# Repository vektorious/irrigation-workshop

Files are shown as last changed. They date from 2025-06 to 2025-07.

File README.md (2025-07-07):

   # Irrigation Workshop

## Introduction
In this workshop, we will build an automated plant watering system. It will consist of four key components:
1. Sensor – measures soil moisture
2. Pump – delivers water to the plant
3. Controller – reads sensor data and controls the pump
4. Interface – let's you control and monitor the system

Together, these parts create a responsive system that waters a plant only when it needs it.

### Soil Moisture Sensors

#### Overview

| Sensor Type | Measurement Principle | Advantages | Limitations |
|---|---|---|---|
| Capacitive | Measures dielectric constant of the soil | Durable, accurate | Sensitive to nearby objects and interference |
| Resistive | Measures electrical resistance | Cheap, easy to use | Corrodes over time (potentially toxic) |

In addition to resistive and capacitive sensors, there are more advanced methods used in agriculture and research, such as tensiometers, Time Domain Reflectometry or Frequency Domain Reflectometry TDR/FDR sensors, and thermal or capillary-based systems. These offer higher accuracy or different measurement principles (like soil water tension) but are often more complex or expensive.

#### DIY Sensors

Tension Sensors (e.g. Tensiometer, Capillary Sensor)
- Measure how tightly water is held in the soil.
- Simulate what plants "feel" when extracting water.
- Use porous ceramic tips and water-filled tubes to show suction or pressure changes.
- analog output but requires pressure sensor to read electronically -> fun but complex to integrate.

Resistive Sensors (e.g. Nail Electrodes, Gypsum Block)
- Measure electrical resistance between two conductors.
- Moist soil conducts better, dry soil worse (but soil type/quality has an impact too!).
- Simple to build with nails, wires, or embedded in gypsum for more stability.
- analog output (voltage) which is very easy to read with microcontrollers -> simple and easy to integrate.

Tensiometers provide more biologically meaningful data, but are harder to read electronically. Resistive sensors are easier to connect and automate, making them ideal for basic watering systems.

#### Workshop Sensor Choice
For this workshop I recommend using the an off-the-shelf capacitive sensor. They are are more stable and durable than resistive ones. They don’t corrode as quickly, provide smoother readings, and are widely available as well as affordable. This makes them ideal for beginner projects and long-term use in automated watering systems. There are standard sensors that are sold by various shops (see image below). However, they are often faulty. Check this video before you buy some: [Capacitive Soil Moisture Sensors don't work correctly + Fix for v2.0 v1.2 Arduino ESP32 Raspberry Pi](https://www.youtube.com/watch?app=desktop&v=IGP38bz-K48)

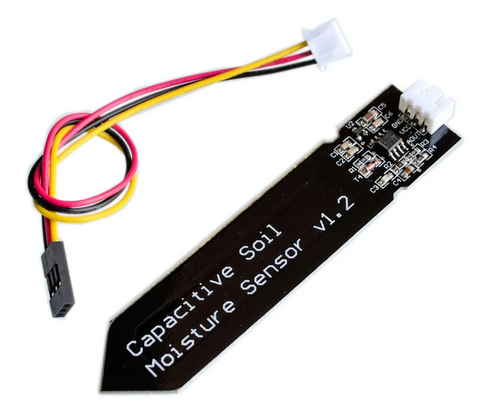
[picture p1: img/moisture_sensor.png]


### Pump Systems

| Pump Type | Working Principle | Advantages | Suitable For |
|---|---|---|---|
| Submersible Pump  | Impeller submerged in water reservoir | High flow rate, robust | Raised beds, greenhouses |
| Diaphragm Pump | Oscillating membrane creates pressure/vacuum  | Stable pressure, self-priming | Distributed watering systems |
| Peristaltic Pump  | Fluid pushed through flexible tube by rollers | Precise dosage, no backflow | Potted plants, indoor setups |

For this workshop, we will use a diaphragm pump. They are reliable, self-priming, and can handle small amounts of water with consistent pressure. They work well in compact systems and are easy to control with a relay or MOSFET. Their sealed design also makes them less prone to leaking or clogging — perfect for small-scale automated irrigation projects.

### Controlling the Pump

Microcontrollers like ESP32 or Arduinos cannot power pumps directly. You need an electronic switch that can handle higher current. There are two common ways to do this: Using a relay or a MOSFET.

| Feature | Relay Module | MOSFET Module |
|---|---|---|
| Switching type | Mechanical (electromagnetic switch) | Electronic (transistor-based) |
| Sound | Audible “click” when switching | Silent |
| Speed | Slow switching (ms range) | Fast switching (μs range), suitable for PWM |
| Load types | Good for AC and DC | Typically used for DC only |
| Efficiency | Some power loss (mechanical contact) | High efficiency, low heat generation |
| Use case example | Simple on/off pump control | Precise or PWM pump control (e.g. speed) |
| Complexity | Easy to wire and understand | Requires correct polarity and pin setup |

For this workshop, we will use a MOSFET (IRLB8721PbF). This logic-level MOSFET can be triggered directly from a microcontroller (e.g. Arduino or micro:bit) and is capable of switching up to 24 V DC and 10 A — more than enough for most small pumps or valves. It's silent, efficient, and ideal for low-voltage DC systems.
While the pumps used in this setup typically draw far less current (around 500 mA), using a higher-rated MOSFET gives us more flexibility. It ensures that the same circuit can also be used safely with larger pumps or other components in future projects.

(Wiring example check [here](https://learn.adafruit.com/rgb-led-strips/usage)) 

NOTE: Pico AND MOSFET/Pump Power Source MUST HAVE THE SAME GROUND!!

### Adding an LED strip as part of the interface

As part of this workshop, we held an open design session with some of the participants before the hands-on activities began. One of their suggestions was to add an LED strip with 10 individually controllable LEDs to visualize the soil moisture level.

We use a WS2812B (NeoPixel-compatible) LED strip, which allows for precise color and brightness control using a single data pin from the microcontroller. 

## Setup and Code

### Wiring the components

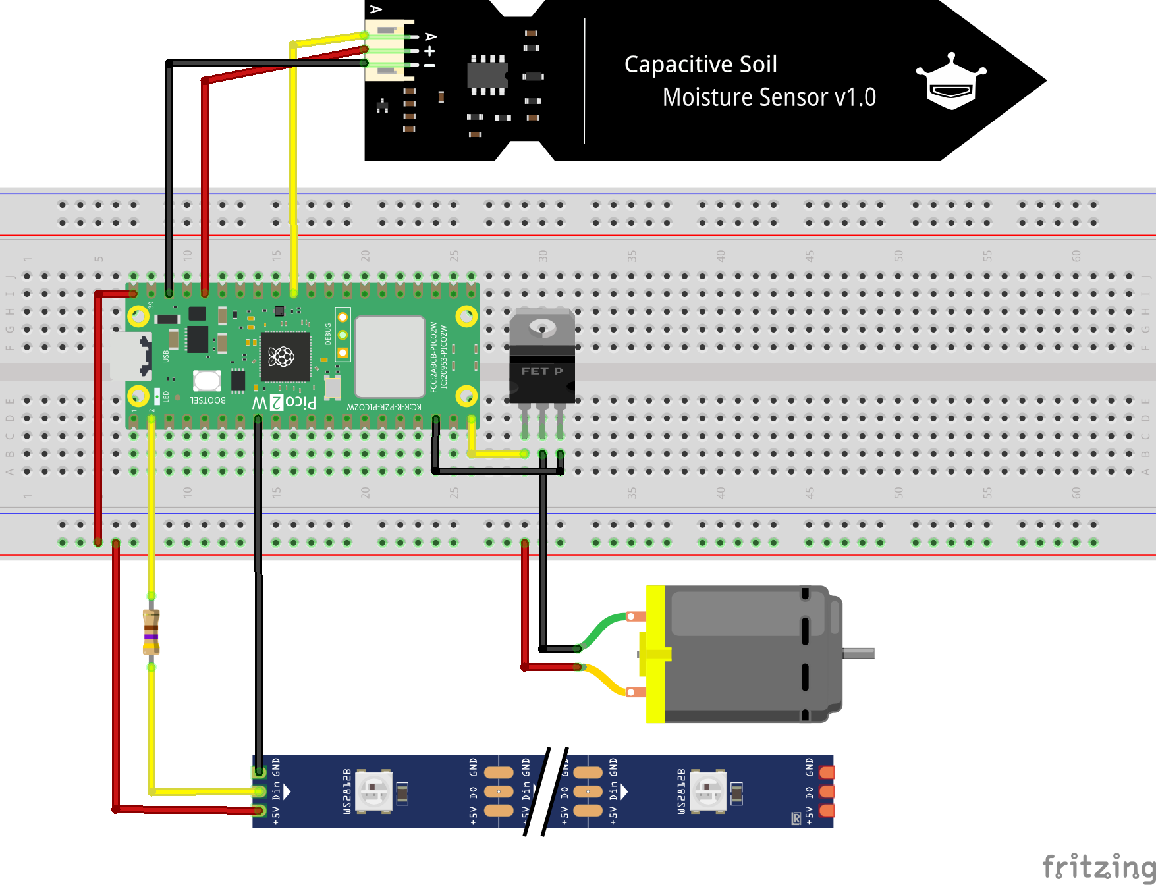
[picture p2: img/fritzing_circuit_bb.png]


### Switch GPIO output on and off

```python
import machine
import time

# Set the pump control pin
PUMP_PIN = 15  # Use GPIO15, change if needed
pump = machine.Pin(PUMP_PIN, machine.Pin.OUT)

def pump_on():
    pump.value(1)  # Set pin HIGH to turn pump ON
    print("Pump ON")

def pump_off():
    pump.value(0)  # Set pin LOW to turn pump OFF
    print("Pump OFF")

# Simple test sequence
while True:
    print("Turning pump ON for 3 seconds...")
    pump_on()
    time.sleep(3)
        
    print("Turning pump OFF for 3 seconds...")
    pump_off()
    time.sleep(3)

```

### Reading Sensor Data

```python
from machine import Pin, ADC
from time import sleep

soil = ADC(Pin(26))

while True:
  soil_value = soil.read_u16() # read value, 0-65535 across voltage range 0.0v - 3.3v
  soil_voltage = (soil_value/65535)*3.3
  print(soil_voltage) 
  sleep(1)

```

### Test LED strips

```python

import machine
import neopixel
import time

# Configuration
NUM_LEDS = 10
PIN = 1
BRIGHTNESS = 100  # 0–255

np = neopixel.NeoPixel(machine.Pin(PIN), NUM_LEDS)

# Helper: apply brightness to RGB
def scale_color(r, g, b, brightness):
    factor = brightness / 255
    return int(r * factor), int(g * factor), int(b * factor)

# Helper: turn off all LEDs
def clear_strip():
    for i in range(NUM_LEDS):
        np[i] = (0, 0, 0)
    np.write()

# List of colors to cycle through
colors = [
    (255, 0, 0),   # Red
    (0, 255, 0),   # Green
    (0, 0, 255)    # Blue
]

# Main running light loop
try:
    color_index = 0
    while True:
        r, g, b = colors[color_index]
        r, g, b = scale_color(r, g, b, BRIGHTNESS)

        # Forward direction
        for i in range(NUM_LEDS):
            clear_strip()
            np[i] = (r, g, b)
            np.write()
            time.sleep(0.1)

        # Backward direction
        for i in range(NUM_LEDS - 2, 0, -1):
            clear_strip()
            np[i] = (r, g, b)
            np.write()
            time.sleep(0.1)

        # Next color
        color_index = (color_index + 1) % len(colors)

except KeyboardInterrupt:
    clear_strip()
    print("Running light stopped.")

```

### Test all Hardware

```python
import machine
import neopixel
import time

# === Configuration ===
ADC_PIN = 26               # GP26 = ADC0
NEOPIXEL_PIN = 1           # GP1
NUM_LEDS = 10
BRIGHTNESS = 0.2           # Scale 0–1

PUMP_PIN = 15              # GP15 for pump
MOISTURE_THRESHOLD = 30.0  # in percent
PUMP_DURATION = 1          # in seconds

MAX_VOLTAGE = 3.0          # Voltage at driest
MIN_VOLTAGE = 0.5          # Voltage at wettest

# === Setup ===
adc = machine.ADC(ADC_PIN)
np = neopixel.NeoPixel(machine.Pin(NEOPIXEL_PIN), NUM_LEDS)

pump = machine.Pin(PUMP_PIN, machine.Pin.OUT)
pump.value(0)  # Ensure pump is off

# === Helper Functions ===

def read_voltage():
    raw = adc.read_u16()  # Range: 0–65535
    voltage = (raw / 65535) * 3.3
    return voltage

def map_voltage_to_percent(voltage):
    voltage = max(min(voltage, MAX_VOLTAGE), MIN_VOLTAGE)
    percent = (MAX_VOLTAGE - voltage) / (MAX_VOLTAGE - MIN_VOLTAGE) * 100
    return round(percent, 1)

def get_color(percent):
    if percent <= 30:
        return (255, 0, 0)         # Red
    elif percent <= 50:
        return (255, 180, 0)       # Yellow
    else:
        return (0, 255, 0)         # Green

def show_leds(percent):
    leds_on = round(percent / 100 * NUM_LEDS)
    color = get_color(percent)
    for i in range(NUM_LEDS):
        np[i] = color if i < leds_on else (0, 0, 0)
    np.write()

# === Main Loop ===
COOLDOWN = 5  # seconds to wait before retrying pump

try:
    while True:
        voltage = read_voltage()
        percent = map_voltage_to_percent(voltage)
        print("Moisture: {:.1f}% (Voltage: {:.2f} V)".format(percent, voltage))
        
        show_leds(percent)

        if percent < MOISTURE_THRESHOLD:
            print("Moisture below threshold — starting pump.")
            pump.value(1)
            time.sleep(PUMP_DURATION)
            pump.value(0)
            print("Pump stopped.")
            print("Waiting for moisture to improve...")
            time.sleep(COOLDOWN)
        else:
            time.sleep(1)

except KeyboardInterrupt:
    print("Stopped by user.")
    pump.value(0)
    for i in range(NUM_LEDS):
        np[i] = (0, 0, 0)
    np.write()

```

## Interfaces

## Similar Projects

### Self-Watering Flower Pot "Flaura"
This 3D-printable self-watering flower pot project integrates a soil moisture sensor, a microcontroller (ESP8266), and a small water pump to automate plant care. It also includes a mobile app interface using Blynk, allowing users to monitor soil moisture and trigger manual watering remotely.

https://www.thingiverse.com/thing:4921885

### Watering System without microcontroller
This project builds a simple automatic plant watering system without using a microcontroller. It uses soil probes to detect moisture, a BC547 transistor to trigger a relay, and a small water pump. When the soil is dry, the pump automatically turns on; when the soil is wet, it turns off. It's a low-cost solution with no programming required.

https://circuitdigest.com/electronic-circuits/automatic-plant-watering-system-without-arduino

### Elecrow Smart Plant

A compact IoT plant monitor built around an ESP32‑S2 microcontroller, featuring a built‑in capacitive soil moisture probe, ambient light and air temperature/humidity sensors, and an optional 2.9″ e‑paper display for live data. It streams data over Wi‑Fi (compatible with Home Assistant via ESPHome) and is ideal for visualizing plant health, though it does not include a pump or watering system

https://www.elecrow.com/smart-plant.html

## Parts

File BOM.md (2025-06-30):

Soil Moisture Sensor, https://www.berrybase.de/analoger-kapazitiver-bodenfeuchtesensor
Rasberry Pi Pico 2W, https://www.berrybase.de/raspberry-pi-pico-2w-rp2350-wlan-bluetooth-mikrocontroller-board
Micro-USB Cable, https://www.berrybase.de/offizielles-raspberry-pi-micro-usb-kabel-schwarz-1-0m
BME280 Sensor, https://www.berrybase.de/gy-bme280-breakout-board-3in1-sensor-fuer-temperatur-luftfeuchtigkeit-und-luftdruck
Circuit Board, https://www.berrybase.de/lochrasterplatine-doppelseitig-3x7cm-10-stueck
Drehpotentiometer, https://www.berrybase.de/drehpotentiometer-100ko-horizontal-mono-6mm-loetoesen
Photoresistor, https://www.berrybase.de/5506-ldr-fotowiderstand-90mw-2-6ko-540nm-tht
MOSFET (IRLB8721PbF)
Membrane Pump (5 VDC)

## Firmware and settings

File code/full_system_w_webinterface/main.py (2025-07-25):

import network, ujson, utime, machine, urequests, socket, gc
from neopixel import NeoPixel
from machine import Pin, ADC, Timer
import ntptime

# === setup pins ===
MOISTURE_PIN = ADC(26)  # A0
PUMP_PIN = Pin(15, Pin.OUT)
LED_PIN = Pin(1, Pin.OUT)
NUM_LEDS = 10
np = NeoPixel(LED_PIN, NUM_LEDS)

# === Globale Variablen ===
history = []
last_pump_time = None
pump_history = []
config = {}

# === load config ===
def load_config():
    global config, mode
    try:
        with open("config.json", "r") as f:
            config = ujson.load(f)
    except:
        import config as fallback
        config = fallback.default_config
    mode = config.get("mode", "interval")

# === WiFi connection ===
def connect_wifi():
    import secrets
    print("connecting to WiFi")
    wlan = network.WLAN(network.STA_IF)
    wlan.active(True)
    wlan.connect(secrets.WIFI_SSID, secrets.WIFI_PASSWORD)
    while not wlan.isconnected():
        utime.sleep(0.5)
    print("WiFi connected:", wlan.ifconfig())
    ntptime.settime()

# === Measurements ===
def read_moisture():
    raw = MOISTURE_PIN.read_u16() * 3.3 / 65535
    min_v = config["min_voltage"]
    max_v = config["max_voltage"]
    percent = max(0, min(100, 100 * (max_v - raw) / (max_v - min_v)))
    return round(percent, 1), round(raw, 2)

# === updated LEDs ===
def update_leds(percent):
    num_on = round(NUM_LEDS * percent / 100)
    for i in range(NUM_LEDS):
        if i < num_on:
            if percent < config["low_threshold"]:
                np[i] = (255, 0, 0)
            elif percent < config["medium_threshold"]:
                np[i] = (255, 150, 0)
            else:
                np[i] = (0, 255, 0)
        else:
            np[i] = (0, 0, 0)
    np.write()

# === send data via API ===
def send_data(percent, voltage):
    try:
        import secrets
        headers = {"x-api-key": secrets.API_KEY}
        data = {
            "name": config["name"],
            "sensors": {
                "moisture": {
                    "value": percent,
                    "unit": "%"
                    },
                "moisture-voltage": {
                    "value": voltage,
                    "unit": "V"
                    }
                }
            }
        r = urequests.post(secrets.API_URL + "/measurements", headers=headers, json=data)
        print("Status code:", r.status_code)
        r.close()
    except Exception as e:
        print("API error:", e)

def notify_pump():
    try:
        import secrets
        headers = {"x-api-key": secrets.API_KEY}
        data = {"name": config["name"]}
        r = urequests.post(secrets.API_URL + "/pump", headers=headers, json=data)
        print("Status code:", r.status_code)
        r.close()
    except Exception as e:
        print("Pump notify error:", e)

# === pump control ===
def activate_pump():
    global last_pump_time
    last_pump_time = utime.time()
    pump_history.append(last_pump_time)
    if len(pump_history) > 10:
        pump_history.pop(0)
    duration = config["pump_duration"]
    print("activating pump")
    PUMP_PIN.on()
    utime.sleep(duration)
    PUMP_PIN.off()
    last_pump_time = utime.time()
    notify_pump()
    

# === watering decision ===
def check_watering(percent):
    if percent < config["moisture_threshold"]:
        # z. B. max. 1x pro Stunde gießen
        now = utime.time()
        if not last_pump_time or (now - last_pump_time) > 3600:
            activate_pump()

# === start measurement ===
def measure_and_act():
    global history
    percent, voltage = read_moisture()
    print("Feuchtigkeit:", percent, "% (", voltage, "V)")
    update_leds(percent)
    send_data(percent, voltage)
    history.append((percent, voltage, utime.time()))
    if len(history) > 10:
        history.pop(0)
    check_watering(percent)

# === check time (scheduler mode) ===
def should_run_now():
    now = utime.localtime(utime.time()+ int(2 * 3600)) # UTC offset * seconds
    hhmm = "{:02}:{:02}".format(now[3], now[4])
    print(hhmm)
    return hhmm in config["daily_times"]

# === webinterface ===
def start_webserver():
    import json
    addr = socket.getaddrinfo('0.0.0.0', 80)[0][-1]
    s = socket.socket()
    s.bind(addr)
    s.listen(1)
    print("Web interface active…")

    while True:
        try:
            cl, _ = s.accept()
            req = cl.recv(1024).decode()
            print("Request:", req.split("\r\n")[0])

            if "GET /data" in req:
                response = {
                    "history": history,
                    "last_pump": last_pump_time,
                    "pump_history": pump_history,
                    "mode": mode
                }
                body = json.dumps(response)
                cl.send("HTTP/1.0 200 OK\r\nContent-Type: application/json\r\n\r\n" + body)

            elif "POST /update" in req:
                length = 0
                for line in req.split("\r\n"):
                    if line.startswith("Content-Length:"):
                        length = int(line.split(":")[1].strip())
                        break
                body = cl.recv(length).decode()
                updates = json.loads(body)
                config.update(updates)
                with open("config.json", "w") as f:
                    json.dump(config, f)
                cl.send("HTTP/1.0 200 OK\r\n\r\nOK")

            elif "POST /pump" in req:
                activate_pump()
                cl.send("HTTP/1.0 200 OK\r\n\r\nPump started")

            elif "GET /" in req or "GET /index.html" in req:
                cl.send("HTTP/1.0 200 OK\r\nContent-Type: text/html\r\n\r\n")
                try:
                    with open("index.html", "r") as f:
                        for line in f:
                            cl.send(line)
                except Exception as e:
                    print("HTML file error:", e)
                    cl.send("Error loading page.")

            else:
                cl.send("HTTP/1.0 404 Not Found\r\n\r\nNot found")

        except Exception as e:
            print("Unhandled error in webserver thread:", e)

        finally:
            try:
                cl.close()
            except:
                pass
            gc.collect()


# === main loop ===
load_config()
connect_wifi()

# run webinterface in the background
import _thread
_thread.start_new_thread(start_webserver, ())

# scheduler for measurements
last_measure = 0

while True:
    now = utime.time()

    if mode == "test":
        if now - last_measure >= 10:
            measure_and_act()
            last_measure = now

    elif mode == "interval":
        interval_seconds = int(config.get("interval_hours", 1) * 3600)
        if now - last_measure >= interval_seconds:
            measure_and_act()
            last_measure = now

    elif mode == "daily":
        # Only run if we're within a minute of a desired time
        if should_run_now():
            if now - last_measure >= 60:
                measure_and_act()
                last_measure = now

    utime.sleep(5)  # small delay to avoid burning CPU

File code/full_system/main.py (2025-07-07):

# main.py – Pico main loop
import machine
import time
from config import load_config
from secrets import SECRETS
from http_client import post_moisture, post_pump_event
import neopixel

# === Setup ===
config = load_config()

DEVICE_NAME = config["device_name"]
MODE = config["mode"]
THRESHOLD = config["moisture_threshold"]
PUMP_DURATION = config["pump_duration"]
INTERVAL = config["measure_interval"]
MAX_VOLTAGE = config.get("max_voltage", 3.0)
MIN_VOLTAGE = config.get("min_voltage", 0.5)
LOW_THRESHOLD = config.get("low_threshold", 30)
MEDIUM_THRESHOLD = config.get("medium_threshold", 50)
LED_BRIGHTNESS = config.get("led_brightness", 1.0)  # scale 0.0–1.0

adc = machine.ADC(26)
pump = machine.Pin(15, machine.Pin.OUT)
pump.value(0)

np = neopixel.NeoPixel(machine.Pin(1), 10)  # GP1, 10 LEDs

# === WiFi Setup ===
import network
wlan = network.WLAN(network.STA_IF)
wlan.active(True)
wlan.connect(SECRETS["wifi_ssid"], SECRETS["wifi_password"])

print("Connecting to WiFi...")
while not wlan.isconnected():
    time.sleep(0.5)
print("Connected, IP:", wlan.ifconfig()[0])

# === Helper Functions ===
def read_moisture():
    voltage = adc.read_u16() / 65535 * 3.3
    voltage = max(min(voltage, MAX_VOLTAGE), MIN_VOLTAGE)
    percent = (MAX_VOLTAGE - voltage) / (MAX_VOLTAGE - MIN_VOLTAGE) * 100
    return round(percent, 1), round(voltage, 2)

def run_pump():
    print("Pump ON")
    pump.value(1)
    time.sleep(PUMP_DURATION)
    pump.value(0)
    print("Pump OFF")
    post_pump_event()

def scale_color(rgb, brightness):
    return tuple(int(c * brightness) for c in rgb)

def get_color(percent):
    if percent <= LOW_THRESHOLD:
        return scale_color((255, 0, 0), LED_BRIGHTNESS)         # Red
    elif percent <= MEDIUM_THRESHOLD:
        return scale_color((255, 180, 0), LED_BRIGHTNESS)       # Yellow
    else:
        return scale_color((0, 255, 0), LED_BRIGHTNESS)         # Green

def show_leds(percent):
    leds_on = round(percent / 100 * len(np))
    color = get_color(percent)
    for i in range(len(np)):
        np[i] = color if i < leds_on else (0, 0, 0)
    np.write()

# === Main Loop ===
try:
    while True:
        percent, voltage = read_moisture()
        print("Moisture:", percent, "% (", voltage, "V)")
        post_moisture(percent, voltage)
        show_leds(percent)

        if percent < THRESHOLD:
            run_pump()
            time.sleep(5)  # short cooldown
        else:
            time.sleep(INTERVAL if MODE == "test" else 3600)

except KeyboardInterrupt:
    pump.value(0)
    for i in range(len(np)):
        np[i] = (0, 0, 0)
    np.write()
    print("Stopped by user.")

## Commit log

2025-04-27 wirds webserver version
2025-07-03 fixed bug in circuit
    [fritzing_circuit.fzz]
